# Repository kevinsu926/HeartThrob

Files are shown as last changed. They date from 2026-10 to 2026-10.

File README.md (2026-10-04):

# Heartthrob

A heart-shaped ECG board that turns your heartbeat into sound. Touch the two gold electrodes and it plays your ECG as a high-pitched tone, which a phone or laptop can decode using its microphone. It has no Bluetooth, no Wi-Fi and no firmware. 

## How it works

```mermaid
flowchart LR
    A[Fingers on<br/>electrodes] --> B[AD8233<br/>ECG amplifier]
    B --> C[LTC6990<br/>oscillator]
    C --> D[Piezo<br/>~18.5 kHz tone]
    D --> E[Phone / laptop<br/>microphone]
```

1. **Pick up the signal.** One finger from each hand rests on the gold electrodes on each side of the heart. The tiny voltage your heart produces appears between them.
2. **Amplify it.** An AD8233 ECG chip amplifies and filters that signal into a clean waveform.
3. **Turn it into a tone.** The waveform controls an LTC6990 oscillator, so the pitch of an 18.5 kHz tone rises and falls with each heartbeat.
4. **Play it.** A small piezo plays the tone. It is high enough that most adults can't hear it, but phone microphones can.
5. **Decode it.** A phone or laptop listens to the tone, tracks its pitch, and turns it back into a live ECG trace and heart rate.

<p align="center">
  <picture>
    <source media="(prefers-color-scheme: dark)" srcset="hardware/Heartthrob/illustrations/sample-waveform-dark.png">
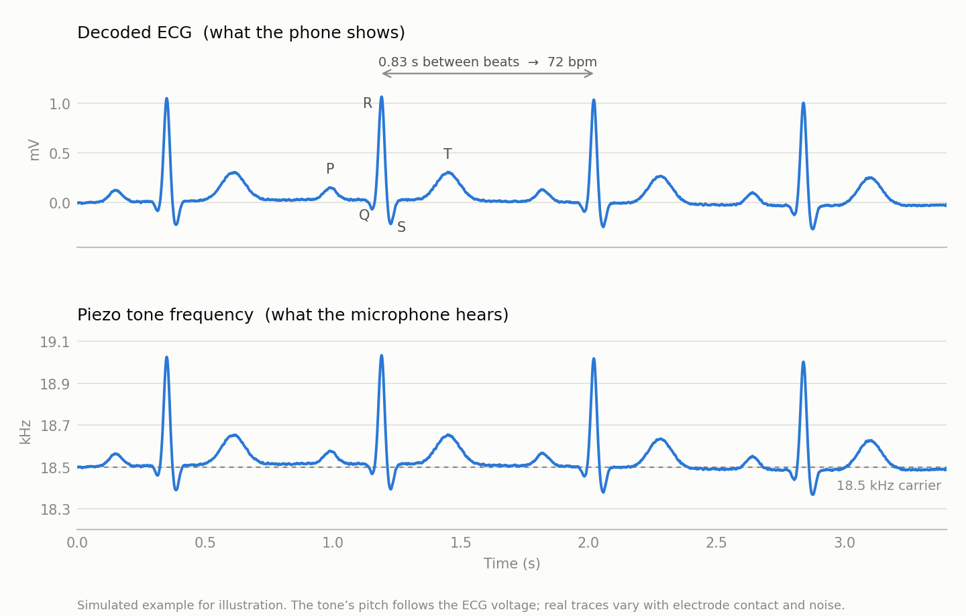
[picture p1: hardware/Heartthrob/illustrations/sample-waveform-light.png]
Simulated decoded ECG and the matching piezo tone frequency
    
  </picture>
</p>

The top trace is what the phone shows: P, QRS and T waves for each beat, with heart rate taken from the time between R peaks. The bottom trace is the same signal as the microphone hears it: a tone near 18.5 kHz whose pitch rises and falls with the ECG. (Simulated example.)

When nobody is touching the electrodes, the board detects that the leads are off and switches the oscillator off to save battery. 

## Power

The board runs on a small 1S LiPo battery soldered to pads on the back, and charges over USB-C. A 3.0 V regulator powers the circuit, and a P-FET protects it if the battery is connected backwards.

## Project structure

- `hardware/Heartthrob/`
  KiCad 10 project: schematic, 4-layer PCB layout, design rules and custom footprints. Open `Heartthrob.kicad_pro`.
- `hardware/Heartthrob/Render/`
  3D renders of the front and back.
- `hardware/Heartthrob/Documentation/`
  Schematic PDF, per-layer PCB plots, and earlier design snapshots in `Archive/`.
- `hardware/Heartthrob/illustrations/`
  Figures used in this README.

> **Note:** This is a hobby project, not a medical device. Don't use it for diagnosis, and don't wear it while it's plugged in to charge.

## Credits

Based on [SiBowald's ECG PCB business card](https://github.com/SiBowald/ecg-pcb-business-card), redesigned by Kevin Su as a rechargeable, heart-shaped board.

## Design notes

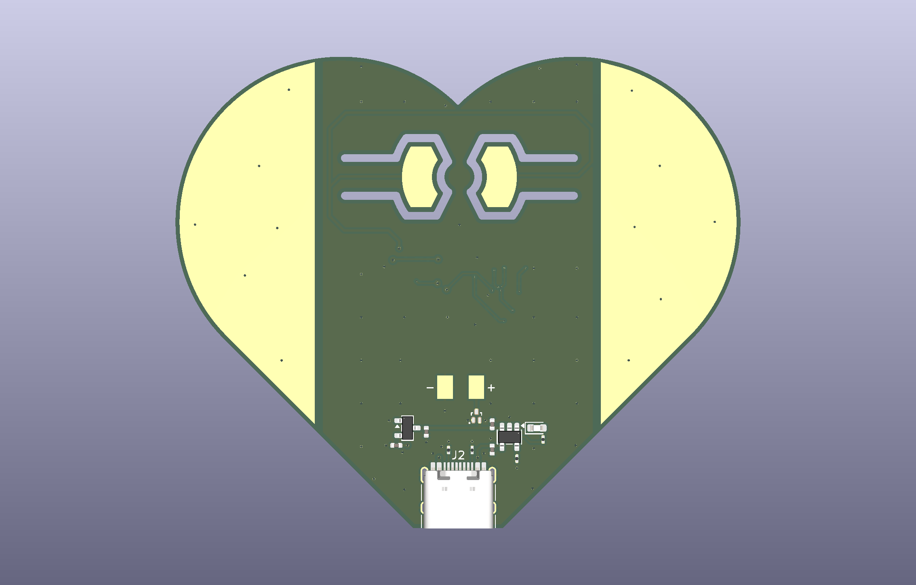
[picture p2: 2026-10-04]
hardware/Heartthrob/Render/Heartthrob_Back.png

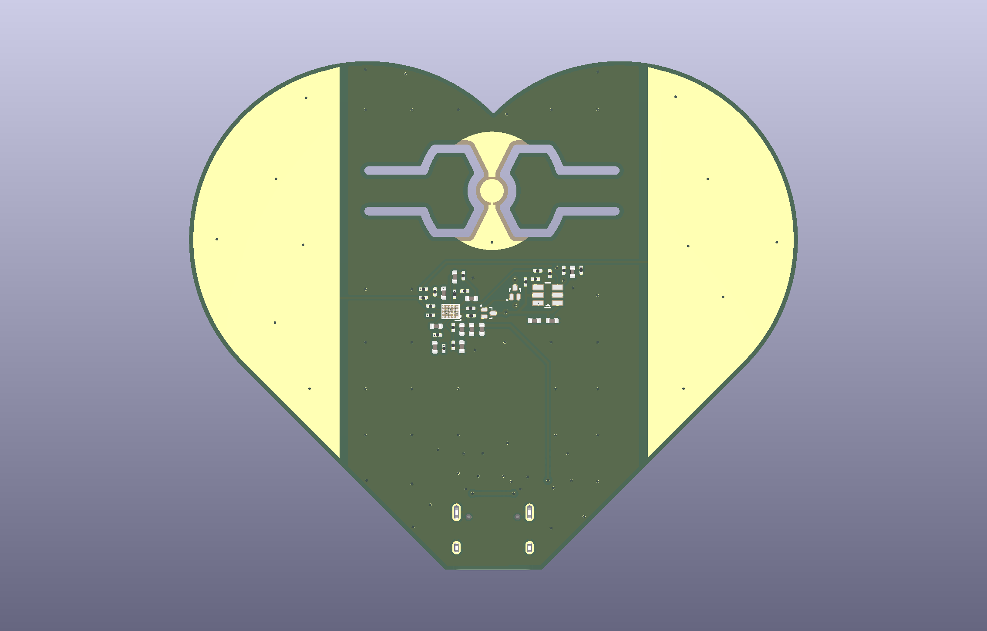
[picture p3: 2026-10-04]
hardware/Heartthrob/Render/Heartthrob_Front.png

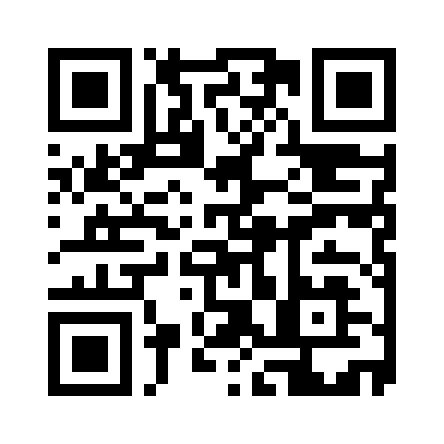
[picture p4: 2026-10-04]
hardware/Heartthrob/illustrations/heartthrob-qr.png

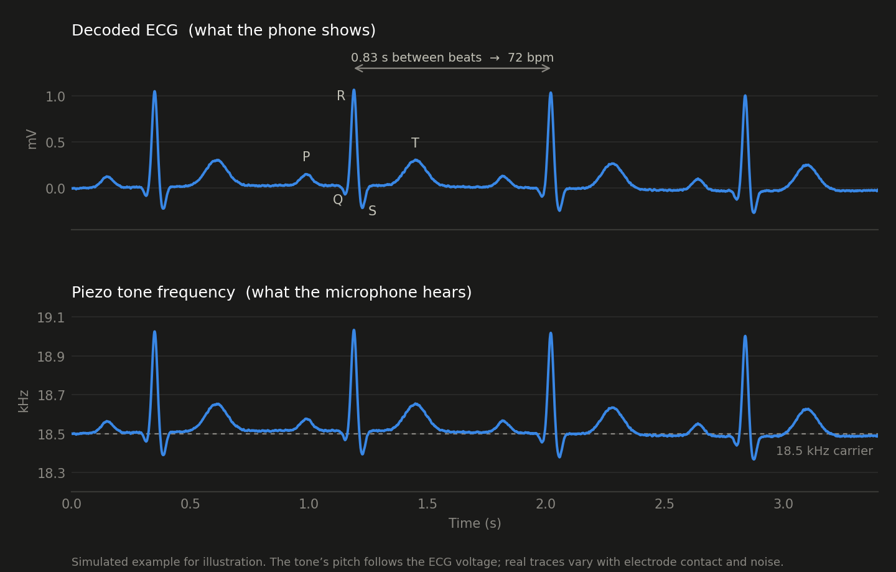
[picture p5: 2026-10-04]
hardware/Heartthrob/illustrations/sample-waveform-dark.png

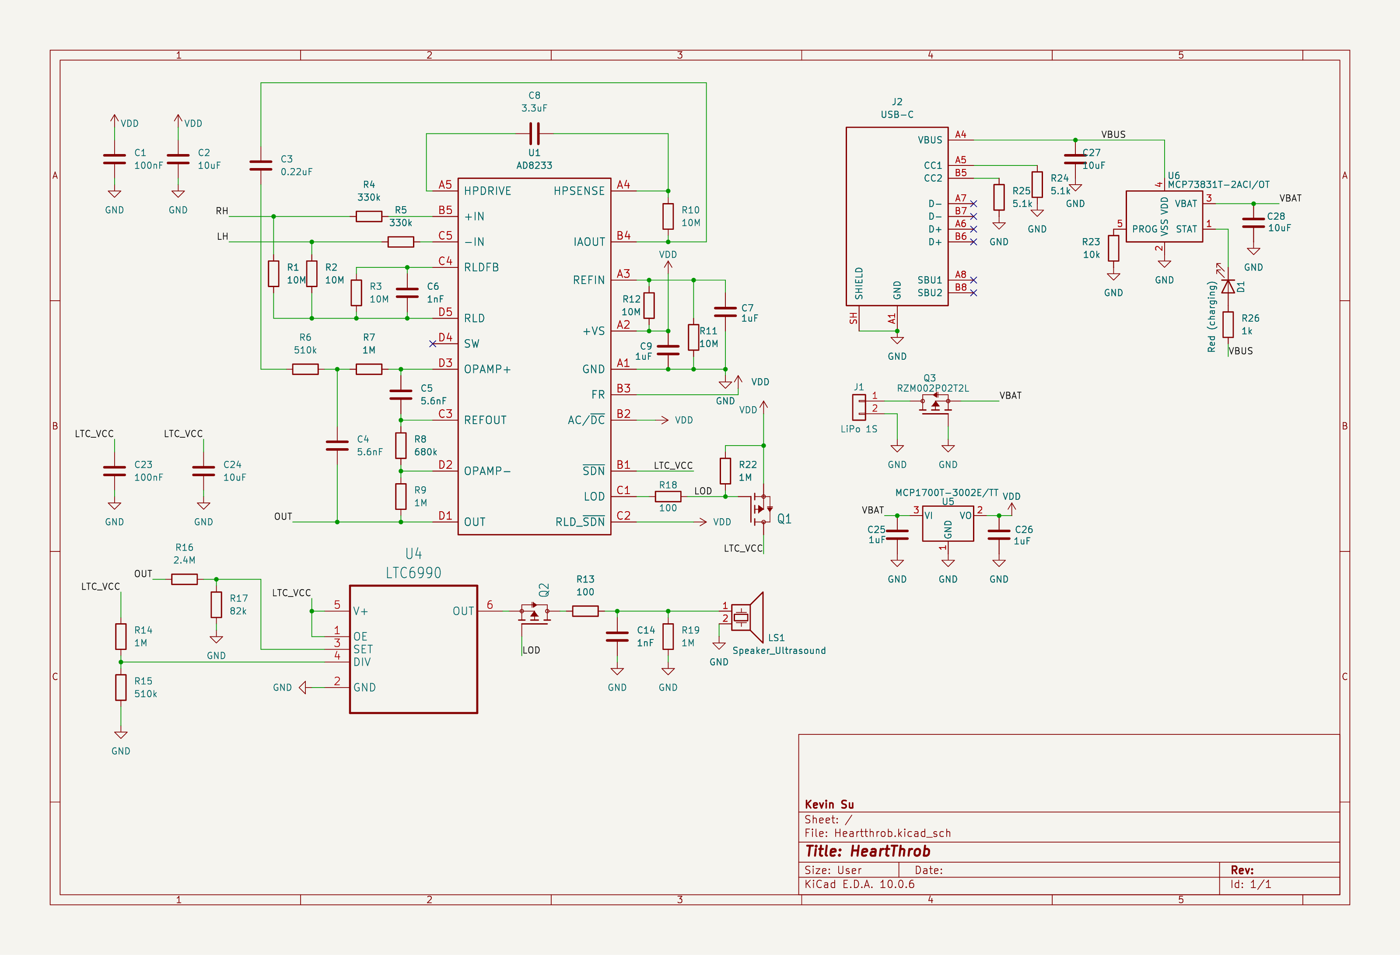
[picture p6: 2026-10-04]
hardware/Heartthrob/illustrations/schematic.png

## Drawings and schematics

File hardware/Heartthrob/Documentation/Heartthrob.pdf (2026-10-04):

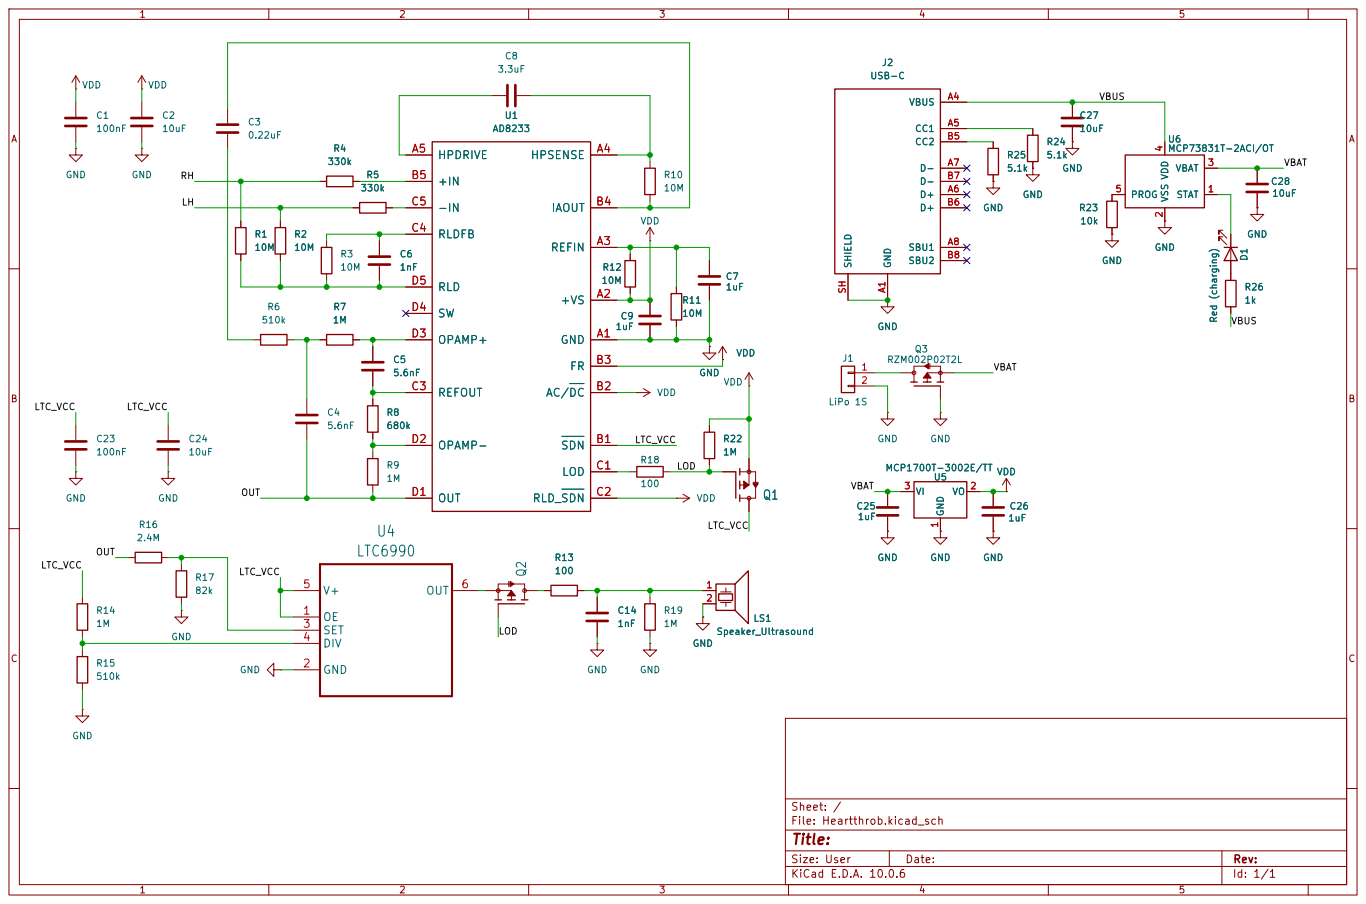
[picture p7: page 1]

Size: User | Rev:
KiCad E.D.A. 10.0.6 | Id: 1/1

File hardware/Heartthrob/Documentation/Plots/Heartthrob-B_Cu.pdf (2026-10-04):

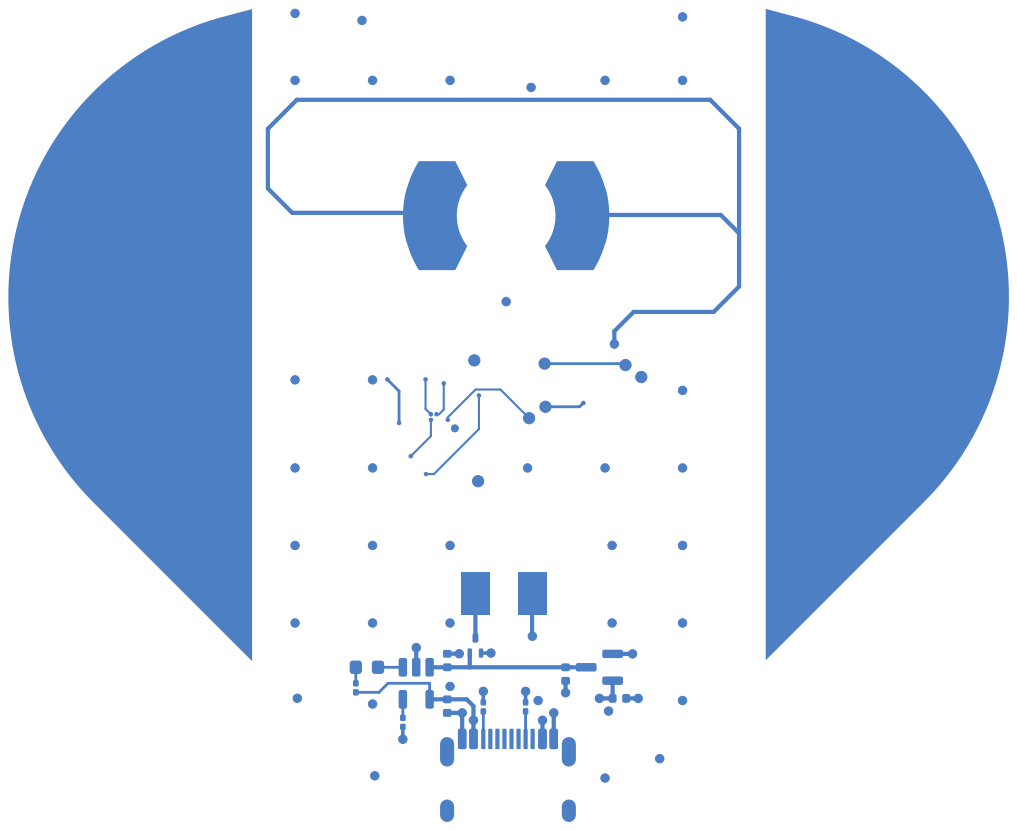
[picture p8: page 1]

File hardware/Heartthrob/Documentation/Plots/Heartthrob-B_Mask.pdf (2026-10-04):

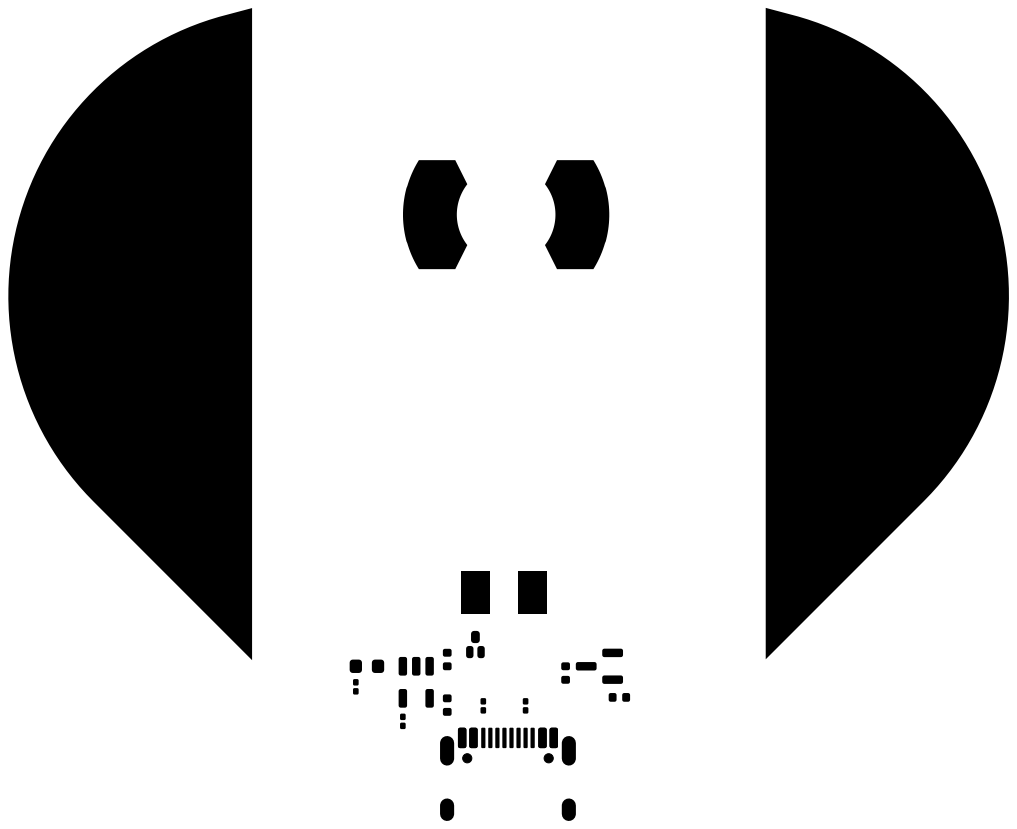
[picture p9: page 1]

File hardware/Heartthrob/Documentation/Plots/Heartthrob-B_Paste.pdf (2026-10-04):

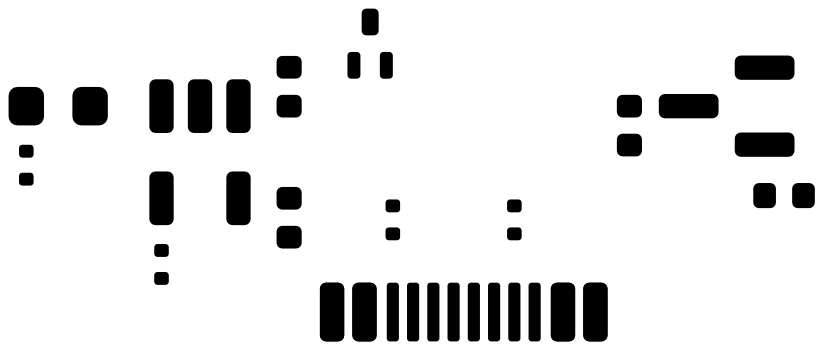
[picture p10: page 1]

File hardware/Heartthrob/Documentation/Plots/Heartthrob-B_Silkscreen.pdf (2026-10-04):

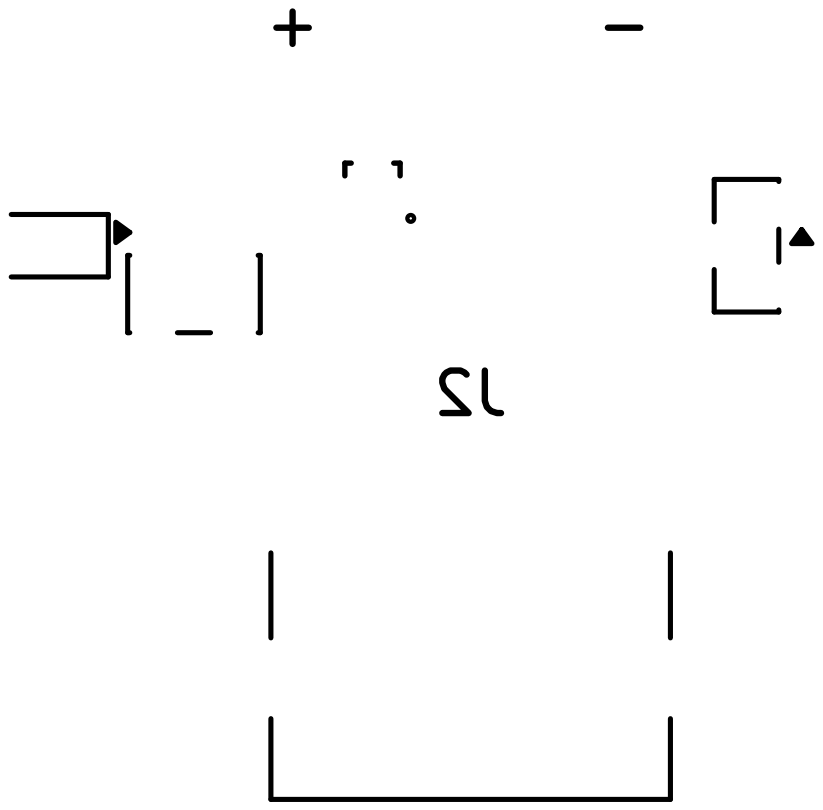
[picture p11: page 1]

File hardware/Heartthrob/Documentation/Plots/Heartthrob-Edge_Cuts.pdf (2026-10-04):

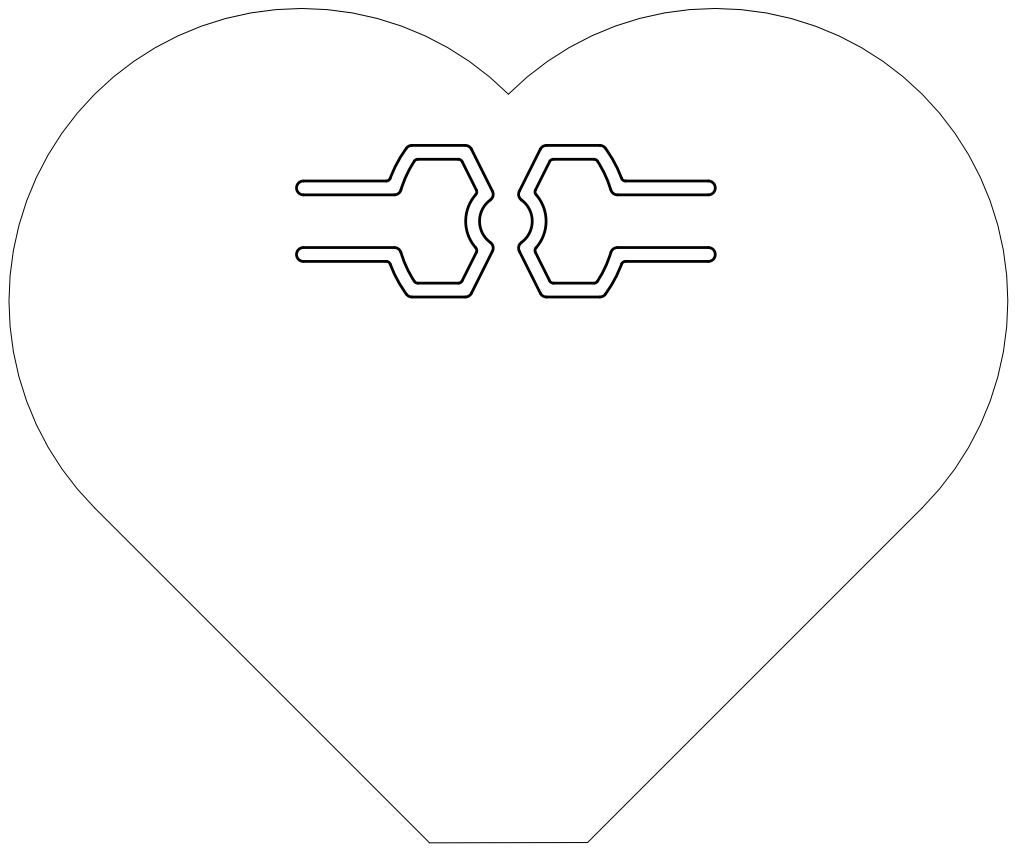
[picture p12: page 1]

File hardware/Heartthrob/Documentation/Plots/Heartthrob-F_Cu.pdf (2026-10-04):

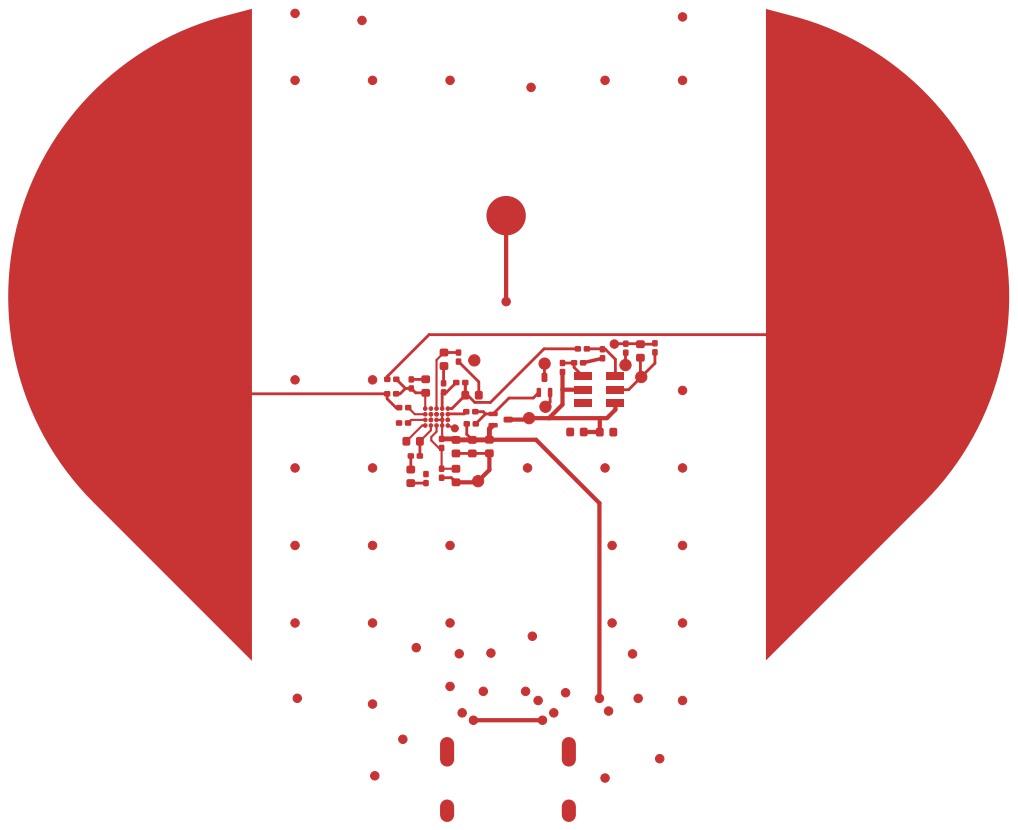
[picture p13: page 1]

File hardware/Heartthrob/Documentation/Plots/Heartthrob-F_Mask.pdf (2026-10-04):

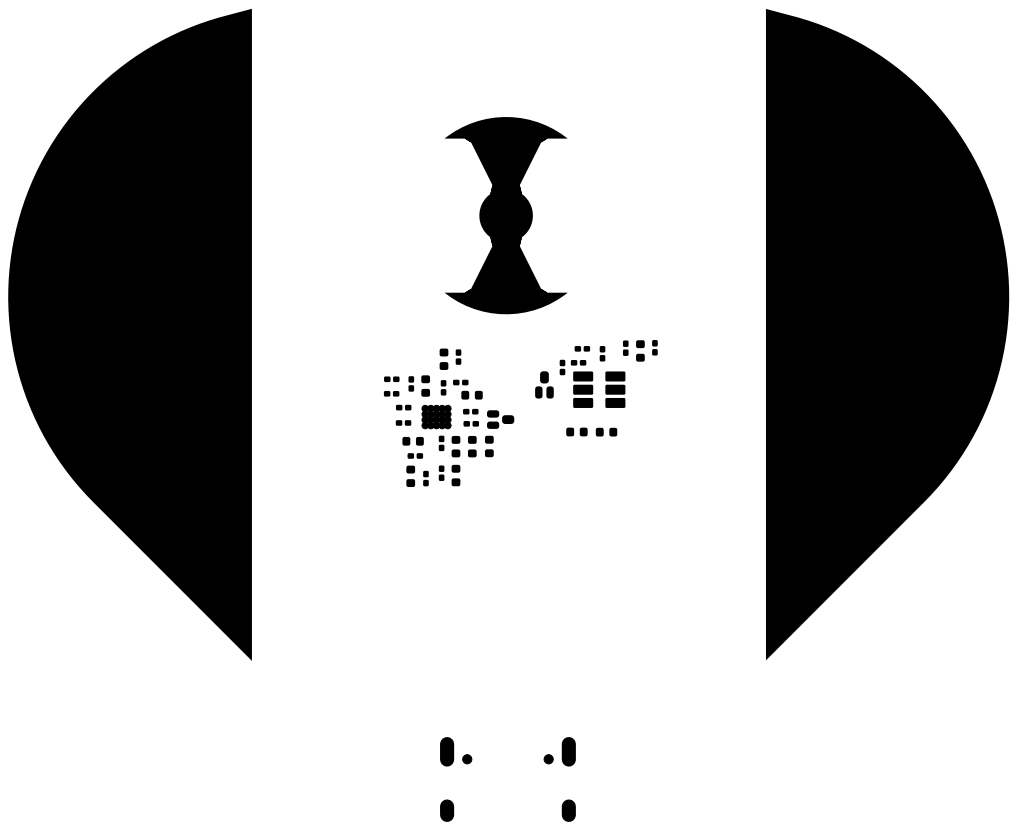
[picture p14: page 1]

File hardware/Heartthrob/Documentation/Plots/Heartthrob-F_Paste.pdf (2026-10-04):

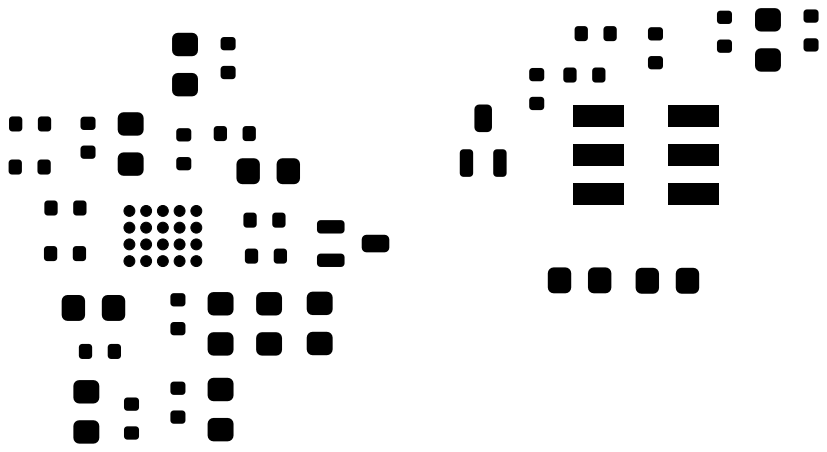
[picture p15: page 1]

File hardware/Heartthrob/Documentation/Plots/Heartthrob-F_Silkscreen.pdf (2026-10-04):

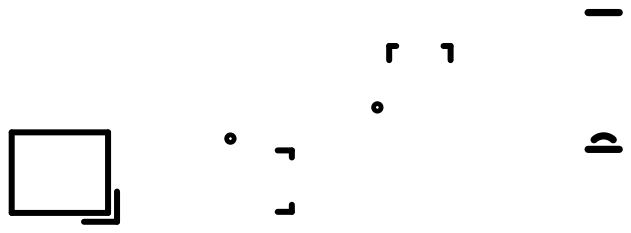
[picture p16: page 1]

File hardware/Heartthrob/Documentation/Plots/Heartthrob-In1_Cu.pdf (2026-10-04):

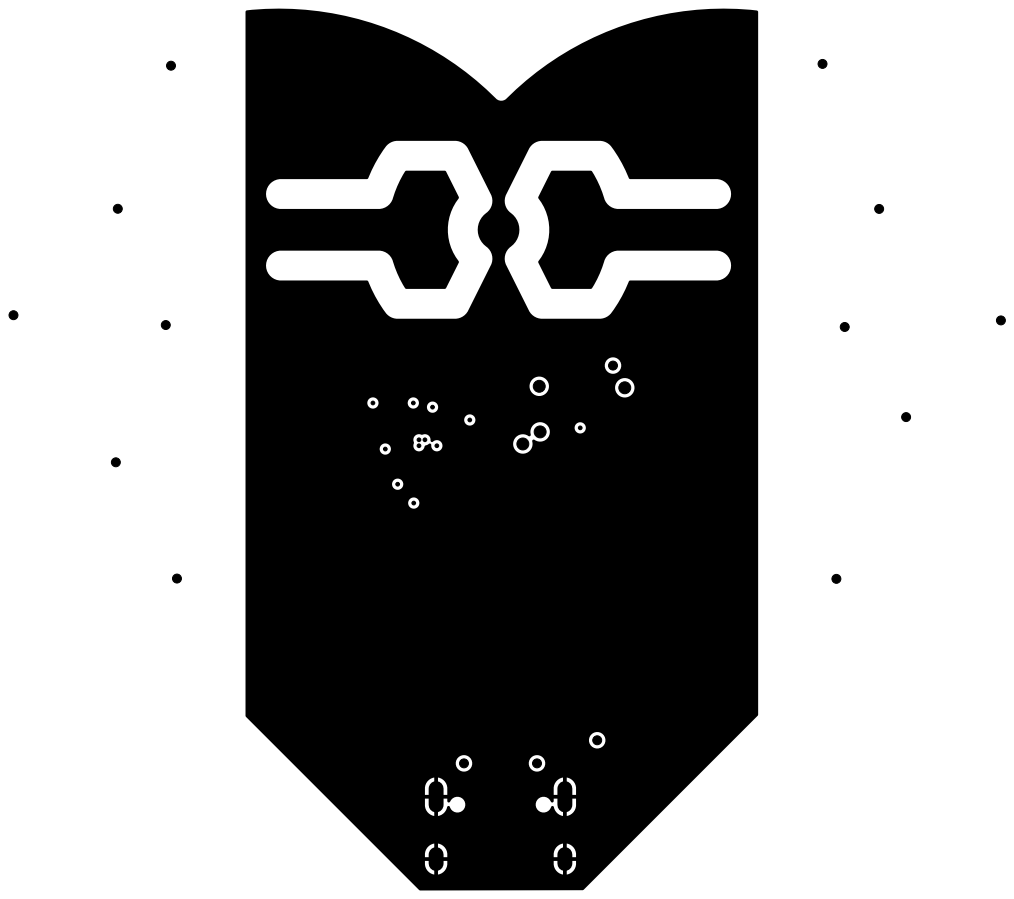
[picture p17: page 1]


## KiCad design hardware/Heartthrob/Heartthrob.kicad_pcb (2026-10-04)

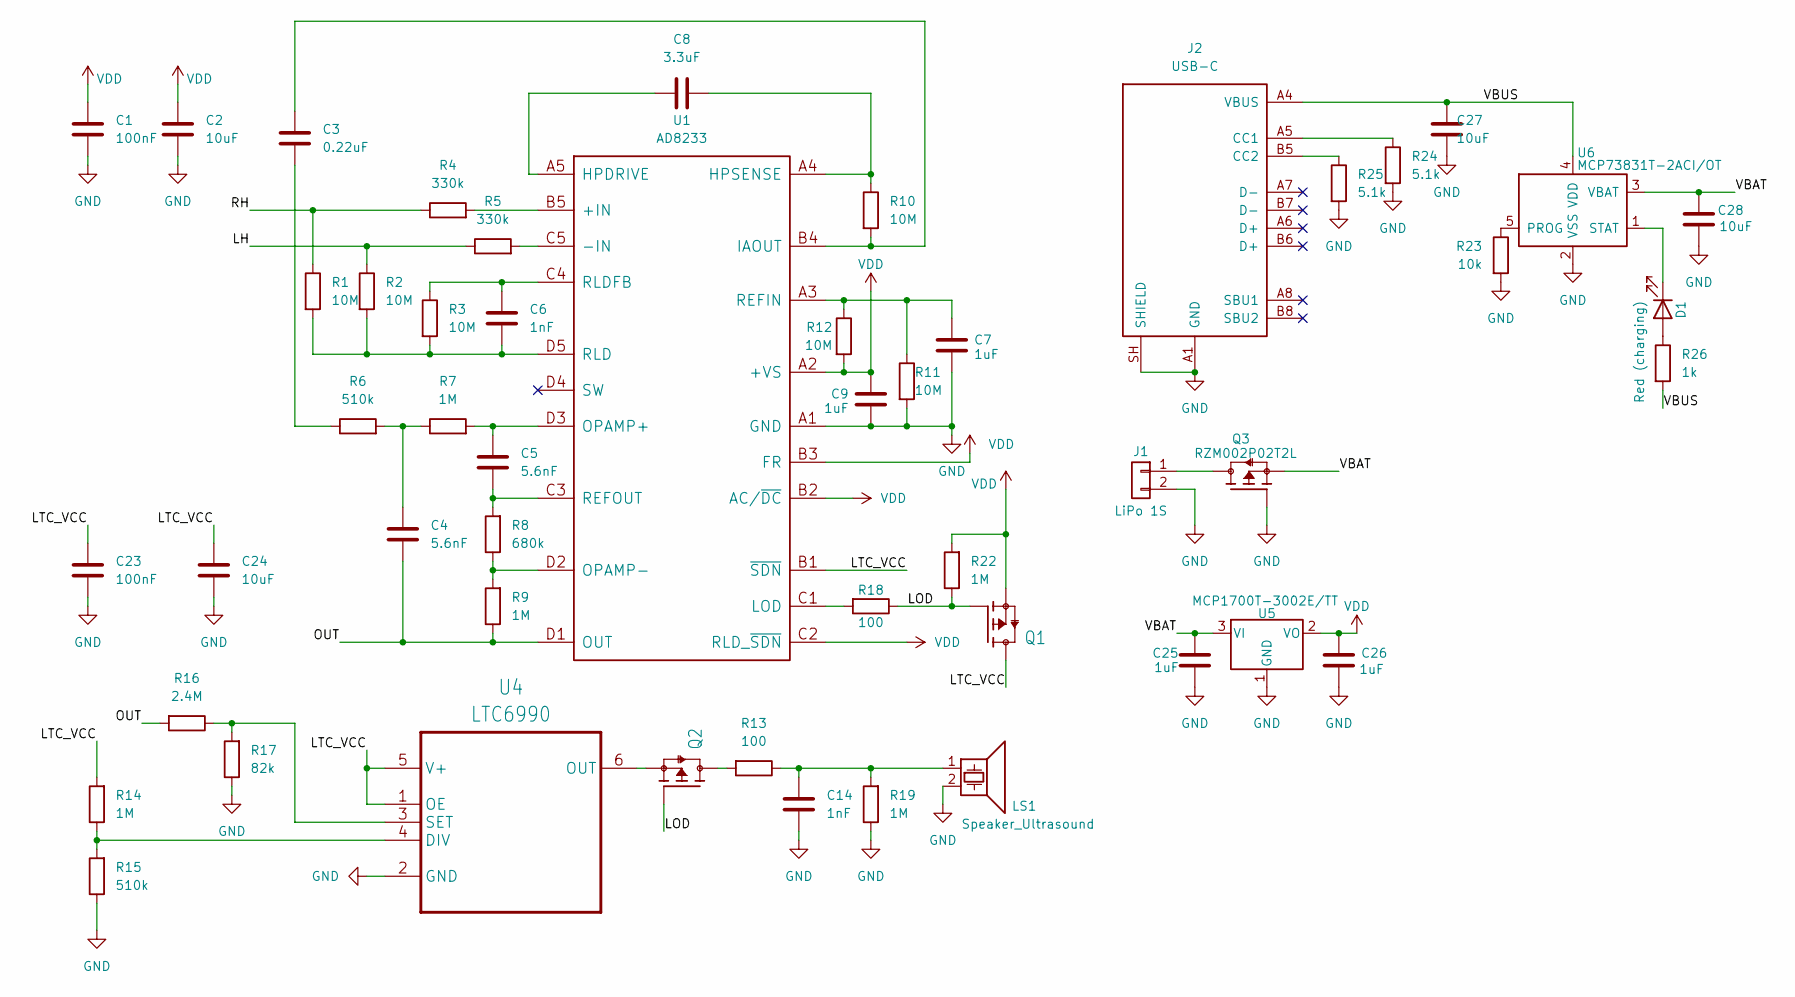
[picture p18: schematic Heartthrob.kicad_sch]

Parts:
C1, C23: 100nF; C_0402_1005Metric; Part Name 100nF 16V Ceramic Cap; LCSC C85857
C2, C24, C27, C28: 10uF; C_0402_1005Metric; Part Name 10uF 6.3V Ceramic Cap; LCSC C412251
C3: 0.22uF; C_0402_1005Metric; Part Name 220nF 16V Ceramic Cap; LCSC C126524
C4, C5: 5.6nF; C_0402_1005Metric; Part Name CAP CER 5.6nF 50V C0G 0402; LCSC C3878619
C6, C14: 1nF; C_0402_1005Metric; Part Name 1nF 50V Ceramic Cap; LCSC C76947
C7, C9, C25, C26: 1uF; C_0402_1005Metric; Part Name 1uF 6.3V Ceramic Cap; LCSC C2167130
C8: 3.3uF; C_0402_1005Metric; Part Name 10V 3.3uF X5R ±10% 0402 Ceramic Capacit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; LCSC C695126
D1: Red (charging); LED_0603_1608Metric; Part Number KT-0603R; LCSC C2286
J1: LiPo 1S; LiPo_SMD_Pads_2x3mm_P4mm
J2: USB-C; USB_C_Receptacle_HRO_TYPE-C-31-M-12; Part Number TYPE-C-31-M-12
LS1: Speaker_Ultrasound; Piezo_12mm; Part Name BUZZER ELEMENT STD 18.5 KHZ 12MM
Q1, Q2, Q3: RZM002P02T2L; SOT-723; Part Name MOSFET P-CH 20V 200MA VMT3
R1, R2, R3, R10, R11, R12: 10M; R_0201_0603Metric; Part Name 10M Film Resistor ±1% 0,05W; LCSC C469663
R4, R5: 330k; R_0201_0603Metric; Part Name 330KΩ ±1% 1/20W ±200ppm/℃; LCSC C142017
R6, R15: 510k; R_0201_0603Metric; Part Name 510KΩ ±1% 1/20W ±200ppm/℃; LCSC C295805
R7, R9, R14, R19, R22: 1M; R_0201_0603Metric; Part Name 1M Film Resistor ±1% 1/20W ±200ppm/℃; LCSC C295786
R8: 680k; R_0201_0603Metric; Part Name 680KΩ ±1% 1/20W ±200ppm/℃; LCSC C226598
R13, R18: 100; R_0201_0603Metric; Part Name 100Ω ±1% 1/20W ±200ppm/℃; LCSC C77623
R16: 2.4M; R_0201_0603Metric; Part Name 2.4M Film Resistor ±1% 50mW; LCSC C474580
R17: 82k; R_0201_0603Metric; Part Name 82k Film Resistor ±1% 1/20W ±200ppm/℃; LCSC C273288
R23: 10k; R_0201_0603Metric; Part Number RC0201FR-0710KL; LCSC C106225
R24, R25: 5.1k; R_0201_0603Metric; Part Number RC0201FR-075K1L; LCSC C274341
R26: 1k; R_0201_0603Metric; Part Number RC0201FR-071KL; LCSC C138165
U1: AD8233; 20-WLCPS-2MMX1.7MM
U4: LTC6990; SOT95P280X100-6N; Part Name Oszillator - Silizium IC 488Hz bis 2MHz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; LCSC C581032
U5: MCP1700T-3002E/TT; SOT-23; Part Number MCP1700T-3002E/TT
U6: MCP73831T-2ACI/OT; SOT-23-5; Part Number MCP73831T-2ACI/OT

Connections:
/LH: R2.1, R5.1
/LOD: Q1.1 (G), Q2.1 (G), R18.1, R22.1
/LTC_VCC: C23.2, C24.2, Q1.3 (D), R14.2, U1.B1 (~SDN), U4.1 (OE), U4.5 (V+)
/OUT: C4.1, R9.1, R16.2, U1.D1 (OUT)
/RH: R1.1, R4.1
/VBAT: C25.1, C28.1, Q3.2 (S), U5.3 (VI), U6.3 (VBAT)
/VBUS: C27.1, J2.A4 (VBUS), J2.A9 (VBUS), J2.B4 (VBUS), J2.B9 (VBUS), R26.2, U6.4 (VDD)
GND: C1.1, C2.1, C7.1, C9.1, C14.1, C23.1, C24.1, C25.2, C26.2, C27.2, C28.2, J1.2, J2.A1 (GND), J2.A12 (GND), J2.B1 (GND), J2.B12 (GND), J2.SH (SHIELD), LS1.2, Q3.1 (G), R11.2, R15.1, R17.1, R19.1, R23.2, R24.2, R25.2, U1.A1 (GND), U4.2 (GND), U5.1 (GND), U6.2 (VSS)
unnamed: C3.1, R6.1
unnamed: C4.2, R6.2, R7.1
unnamed: C14.2, LS1.1, R13.1, R19.2
unnamed: D1.2 (A), R26.1
unnamed: D1.1 (K), U6.1 (STAT)
unnamed: J1.1, Q3.3 (D)
unnamed: J2.A5 (CC1), R24.1
unnamed: J2.B5 (CC2), R25.1
unnamed: Q2.3 (D), R13.2
unnamed: Q2.2 (S), U4.6 (OUT)
unnamed: R4.2, U1.B5 (+IN)
unnamed: R5.2, U1.C5 (-IN)
unnamed: C8.1, U1.A5 (HPDRIVE)
unnamed: C8.2, R10.1, U1.A4 (HPSENSE)
unnamed: C3.2, R10.2, U1.B4 (IAOUT)
unnamed: R18.2, U1.C1 (LOD)
unnamed: C5.2, R7.2, U1.D3 (OPAMP+)
unnamed: R8.1, R9.2, U1.D2 (OPAMP-)
unnamed: C7.2, R11.1, R12.1, U1.A3 (REFIN)
unnamed: C5.1, R8.2, U1.C3 (REFOUT)
unnamed: C6.1, R1.2, R2.2, R3.2, U1.D5 (RLD)
unnamed: C6.2, R3.1, U1.C4 (RLDFB)
unnamed: R14.1, R15.2, U4.4 (DIV)
unnamed: R16.1, R17.2, U4.3 (SET)
unnamed: R23.1, U6.5 (PROG)
VDD: C1.2, C2.2, C9.2, C26.1, Q1.2 (S), R12.2, R22.2, U1.A2 (+VS), U1.B2 (AC/~DC), U1.B3 (FR), U1.C2 (RLD_~SDN), U5.2 (VO)

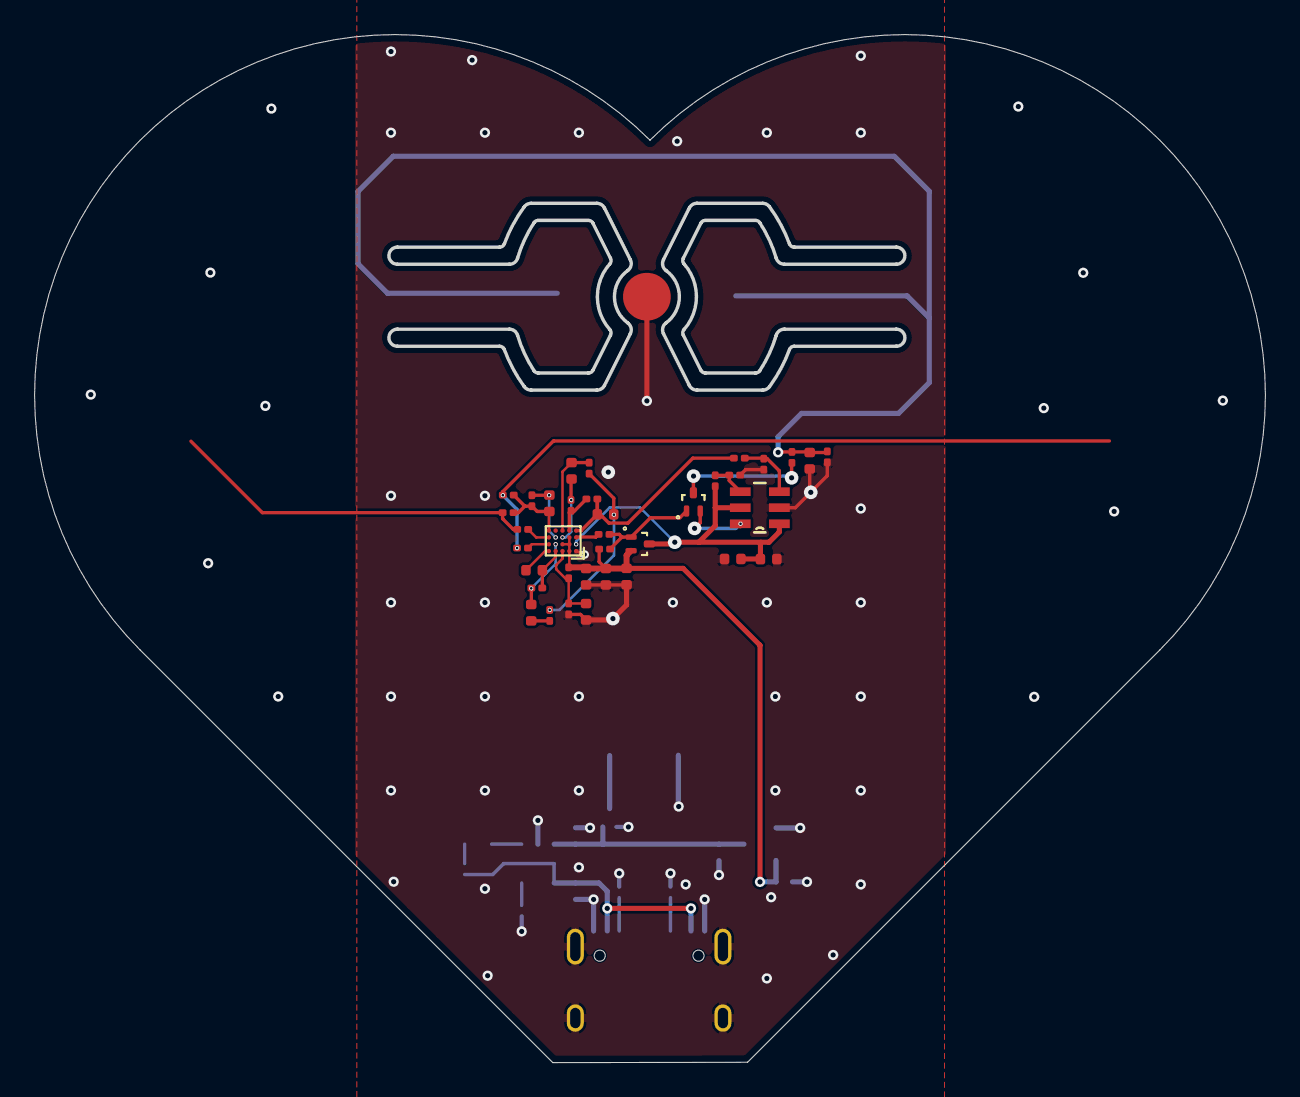
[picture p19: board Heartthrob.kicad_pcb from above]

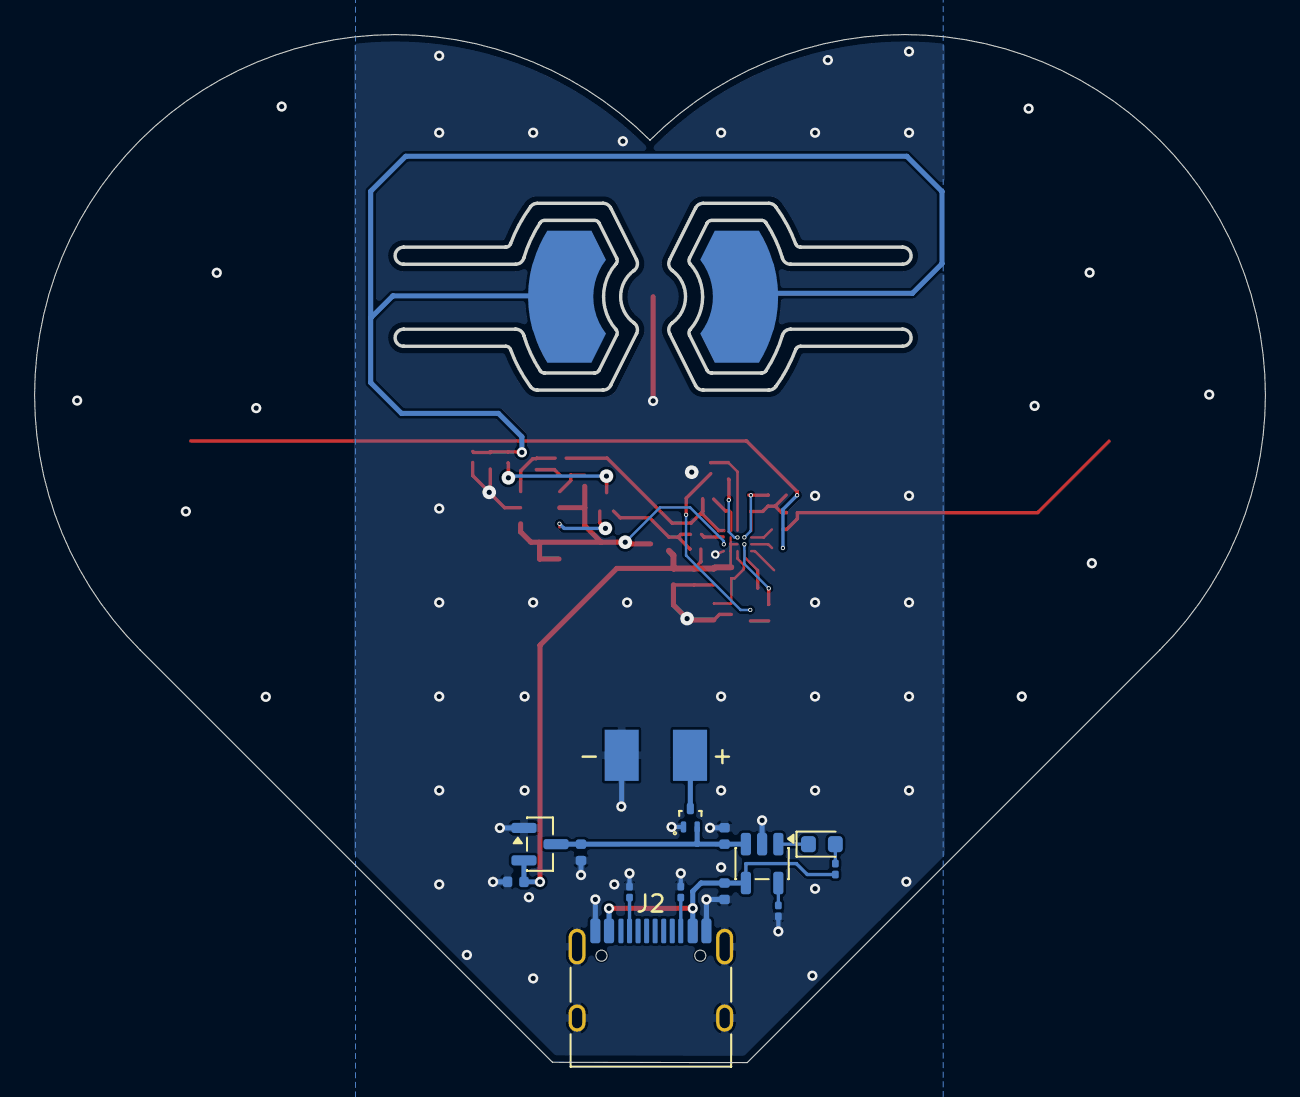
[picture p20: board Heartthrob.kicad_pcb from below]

Board: 4 copper layers, 72.0 x 60.2 mm, 51 parts (14 on the bottom side), 34 nets.
